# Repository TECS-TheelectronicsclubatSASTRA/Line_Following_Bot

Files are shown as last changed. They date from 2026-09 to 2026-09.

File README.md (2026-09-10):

# 🤖 Line-Following Bot — Autonomous PID-Controlled Line Tracker

> An autonomous line-following robot built on the **ESP32**, using a **5-channel IR sensor array** and a **PID control loop** for smooth, adaptive path tracking — including recovery from small gaps and complete line loss.






---

## 📖 Table of Contents

1. [Abstract](#-abstract)
2. [Key Features](#-key-features)
3. [System Architecture](#-system-architecture)
4. [Hardware Components](#-hardware-components)
5. [Pin Diagrams & Wiring](#-pin-diagrams--wiring)
6. [Power Design & Calculations](#-power-design--calculations)
7. [Software Stack](#-software-stack)
8. [Getting Started](#-getting-started)
9. [Firmware Overview](#-firmware-overview)
10. [Control Algorithm Details](#-control-algorithm-details)
11. [Calibration](#-calibration)
12. [Chassis Design](#-chassis-design)
13. [Results](#-results)
14. [Known Limitations & Future Work](#-known-limitations--future-work)
15. [Abbreviations](#-abbreviations)
---

## 🧾 Abstract

This project implements an **autonomous line-following robot** using an **ESP32** microcontroller, a **5-channel IR reflectance sensor array**, and a **TB6612FNG dual motor driver**. A closed-loop **PID (Proportional–Integral–Derivative) controller** continuously computes a weighted position error from the sensor array and translates it into differential motor speeds, allowing the bot to smoothly track a line, correct drift, and navigate curves.

The system also includes **gap-tolerance logic** (to glide over short broken segments of the line) and a **line-recovery routine** (pivoting toward the last known error direction when the line is completely lost). The chassis is a fully custom design, modeled in **Fusion 360**.

---

<p align="center">
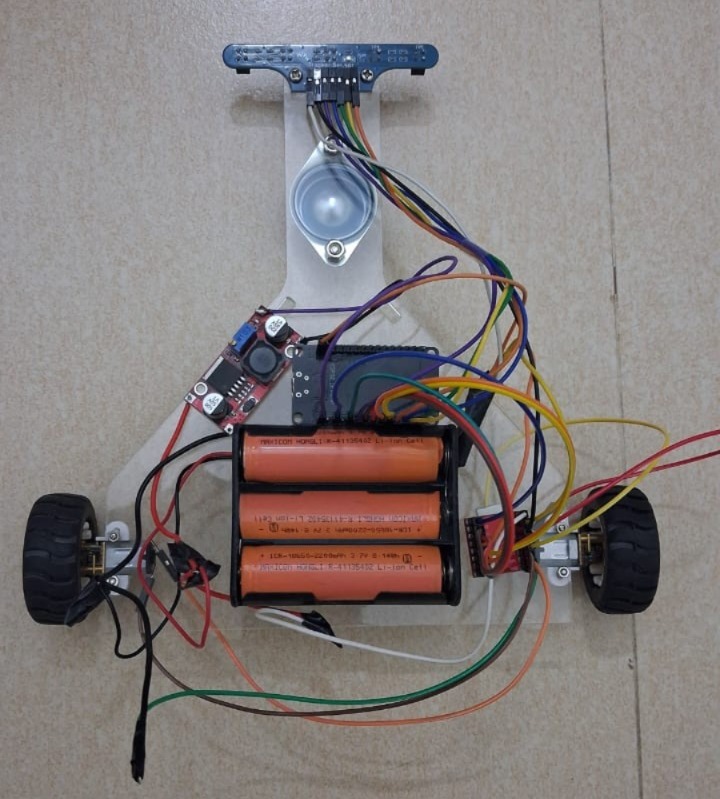
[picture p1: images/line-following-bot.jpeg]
  
</p>

---

## ✨ Key Features

| Feature | Description |
|---|---|
| 🎯 **Weighted Error Calculation** | 5 IR sensors mapped to weights `{-2,-1,0,1,2}` produce a continuous position error, not just discrete on/off states |
| 🧮 **Full PID Control Loop** | Proportional, Integral, and Derivative terms combine to produce smooth, non-oscillatory corrections |
| ⚙️ **Differential Motor Speed Control** | Left/right motor speeds are independently adjusted via PWM based on the computed correction |
| 🕳️ **Gap Tolerance** | Bot continues straight through short line breaks (< 50 ms) instead of veering off |
| 🔄 **Line-Recovery Pivot** | If the line is lost beyond the gap tolerance, the bot pivots in the direction of the last known error until it reacquires the line |
| 🔋 **Isolated Power Domains** | Battery pack powers the motor driver directly; a buck converter steps down voltage for the ESP32 logic rail |
| 🧩 **Custom Chassis** | Fully custom-modeled chassis designed in Fusion 360 |

---

## 🏗️ System Architecture

```
┌────────────────────┐        Analog Voltage (x5)         ┌──────────────────────┐
│  IR Tracker Module │ ──────────────────────────────▶   │        ESP32          │
│  (5 x IR Sensors)  │                                    │  (PID Control Logic) │
└────────────────────┘                                    └──────────┬───────────┘
                                                                     │ PWM + Direction Pins
                                                                     ▼
                                                          ┌────────────────────────┐
                                                          │     TB6612FNG          │
                                                          │   Dual Motor Driver    │
                                                          └───────────┬────────────┘
                                                                      │
                                                        ┌─────────────┴─────────────┐
                                                        ▼                           ▼
                                                 N20 Motor (Left)           N20 Motor (Right)
```

**Data flow summary:**
1. The 5-channel IR array reads analog reflectance values off the track surface.
2. Each reading is thresholded into a binary state (`0` = WHITE, `1` = BLACK / line).
3. Binary states are multiplied by positional weights and averaged to compute a single `error` value representing the bot's offset from the line's center.
4. The `error` is fed through the PID formula to compute a `correction` term.
5. `baseSpeed ± correction` produces independent left/right PWM duty cycles, sent to the TB6612FNG.
6. The TB6612FNG drives the two N20 motors accordingly, steering the bot back toward the line.

---

## 🔩 Hardware Components

| Component | Quantity | Purpose |
|---|---|---|
| ESP32 Development Board | 1 | Central MCU — sensor reading, PID computation, PWM generation |
| Waveshare IR Tracker Module | 5 channels (1 module) | Line detection via analog reflectance sensing |
| TB6612FNG Motor Driver | 1 | Drives both N20 motors with independent PWM + direction control |
| N20 Motor, 12V, 600 RPM | 2 | Drive motors (left & right) |
| 18650 Li-ion Cell | 3 | 11.1V battery pack — primary power source |
| Buck Converter (LM2596-based) | 1 | Steps down 11.1V pack voltage to power the ESP32 logic rail |
| Custom Chassis (Fusion 360) | 1 | Structural frame housing all components |

---

## 🔌 Pin Diagrams & Wiring

### IR Sensor → ESP32

| Sensor Position | Signal | ESP32 Pin |
|---|---|---|
| Far Left (L2) | ir1 | GPIO 27 |
| Left (L1) | ir2 | GPIO 34 |
| Center (C) | ir3 | GPIO 36 (VP) |
| Right (R1) | ir4 | GPIO 39 (VN) |
| Far Right (R2) | ir5 | GPIO 35 |

### TB6612FNG → ESP32

| ESP32 Pin | TB6612FNG Signal | Notes |
|---|---|---|
| GPIO 13 | PWMA | Left motor speed (PWM) |
| GPIO 14 | PWMB | Right motor speed (PWM) |
| GPIO 25 | IN1 | Left motor direction bit 1 |
| GPIO 26 | IN2 | Left motor direction bit 2 |
| GPIO 32 | IN3 | Right motor direction bit 1 |
| GPIO 33 | IN4 | Right motor direction bit 2 |
| GND | GND | Common ground — must tie ESP32, driver, and battery grounds together |

> ⚠️ **Critical wiring rule:** The IR tracker module, ESP32, TB6612FNG, and both battery packs must all share a **common ground**. The buck converter regulates the 11.1V pack down for the ESP32's logic rail; the TB6612FNG and motors are powered directly from the 11.1V pack.

### Full Circuit Diagram

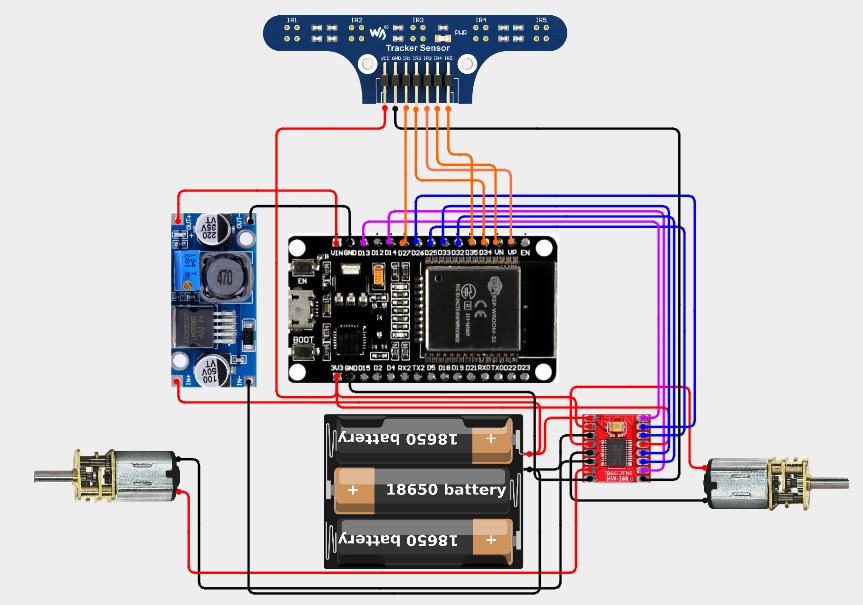
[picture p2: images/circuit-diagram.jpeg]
Circuit Diagram


---

## 🔋 Power Design & Calculations

| Metric | Value | Basis |
|---|---|---|
| Battery pack voltage | 11.1V | 3 × 3.7V 18650 Li-ion cells (series) |
| N20 motor rated voltage | 12V | Slightly under-driven by the 11.1V pack (acceptable — no full-speed requirement) |
| N20 motor rated speed | 600 RPM | At rated voltage, no load |
| ESP32 logic voltage | 3.3V (regulated via onboard LDO) | Fed from buck converter output |
| Motor driver supply (VM) | 11.1V | Direct from battery pack |
| Motor driver logic supply (VCC) | 3.3V–5V | From ESP32 or buck converter rail |

**Design rationale:** The motor driver and motors are powered directly from the 11.1V pack to avoid unnecessary voltage drop, while the ESP32 and sensor logic run off a separate regulated rail via the buck converter — isolating noisy motor current transients from the microcontroller's supply and reducing the risk of brown-outs during motor stalls or direction changes.

---

## 🖥️ Software Stack

| Layer | Technology |
|---|---|
| Firmware | C++ (Arduino framework for ESP32) |
| PWM Generation | ESP32 `ledc` API (`ledcAttach`, `ledcWrite`) |
| Sensing | `analogRead()` on 5 IR channels |
| Control Algorithm | Custom PID implementation (weighted-average error) |
| IDE / Toolchain | Arduino IDE with ESP32 board support |
| Mechanical Design | Autodesk Fusion 360 (chassis, exported as DXF) |

---

## 🚀 Getting Started

### 1. Prerequisites
- [Arduino IDE](https://www.arduino.cc/en/software) with ESP32 board package installed
- USB cable for flashing the ESP32
- Fully assembled hardware per the [Pin Diagrams & Wiring](#-pin-diagrams--wiring) section

### 2. Wiring
Follow the [Pin Diagrams & Wiring](#-pin-diagrams--wiring) section and the circuit diagram above. Double-check common ground across the ESP32, TB6612FNG, and battery packs before powering on.

### 3. Flashing the Firmware
```bash
# In Arduino IDE:
# 1. Select Board: "ESP32 Dev Module"
# 2. Select the correct COM/serial port
# 3. Open the .ino sketch from this repository
# 4. Click Upload
```

### 4. Running the Bot
1. Place the bot on the track with the IR array centered over the line.
2. Power on via the 18650 battery pack.
3. The bot will begin tracking the line immediately using the PID loop.
4. Monitor live sensor/error data via Serial Monitor at `115200` baud.

---

## 🧠 Firmware Overview

### Core Data Structures
```cpp
const int weights[5] = {-2, -1, 0, 1, 2};   // positional weight per sensor
float previousError = 0;
float integralError = 0;
```

### Key Functions

| Function | Role |
|---|---|
| `setMotors(leftSpeed, rightSpeed)` | Sets motor direction pins and writes constrained PWM values to both motors |
| `loop()` | Reads all 5 IR sensors, computes binary states, calculates weighted error, runs the PID formula, and calls `setMotors()` |
| Gap/Recovery block (inside `loop()`) | Detects when all sensors read WHITE; continues straight for short durations, then pivots toward the last known error if the line stays lost |

---

## 🎛 Control Algorithm Details

1. **Binary Thresholding:** Each of the 5 analog readings is compared against a threshold (`1700`). Values above → WHITE (`0`); values below → BLACK (`1`, the line).
2. **Weighted Error:**
   ```
   error = Σ(binary[i] × weight[i]) / Σ(binary[i])
   ```
   This gives a continuous value representing how far off-center the line is — not just "left/right."
3. **PID Correction:**
   ```
   correction = Kp × error + Ki × integralError + Kd × derivative
   ```
   - `Kp = 18`, `Ki = 0.2`, `Kd = 7` (tuned for the current chassis/track)
   - `integralError` is clamped to ±50 to prevent windup
4. **Speed Mapping:**
   ```
   leftSpeed  = baseSpeed + correction
   rightSpeed = baseSpeed - correction
   ```
5. **Gap Tolerance:** If all sensors read WHITE for less than 50 ms, the bot assumes a small gap and continues straight at `baseSpeed`.
6. **Line Recovery:** If the line stays lost beyond 50 ms, the bot pivots in-place toward whichever side `previousError` last indicated, until the line is reacquired.

---

## 🎚 Calibration

The threshold value (`1700`) is tuned for the specific track surface and lighting conditions used during testing. To recalibrate for a different track:

1. Open the Serial Monitor at `115200` baud.
2. Record raw analog readings over plain WHITE surface and over the BLACK line.
3. Set the threshold roughly halfway between the two averages.
4. Re-tune `Kp`, `Ki`, `Kd`, `baseSpeed`, and `pivotSpeed` as needed for the new track's curvature and desired speed.

---

## 🧩 Chassis Design

The chassis was custom-designed in **Fusion 360**.

<p align="center">
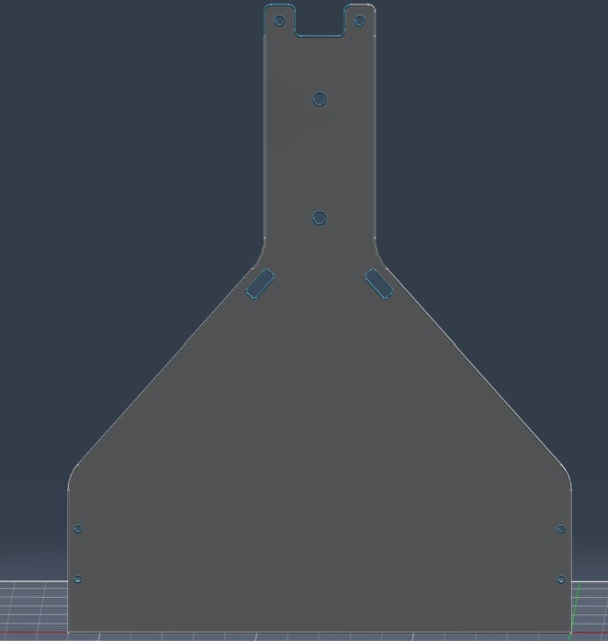
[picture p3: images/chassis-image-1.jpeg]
  
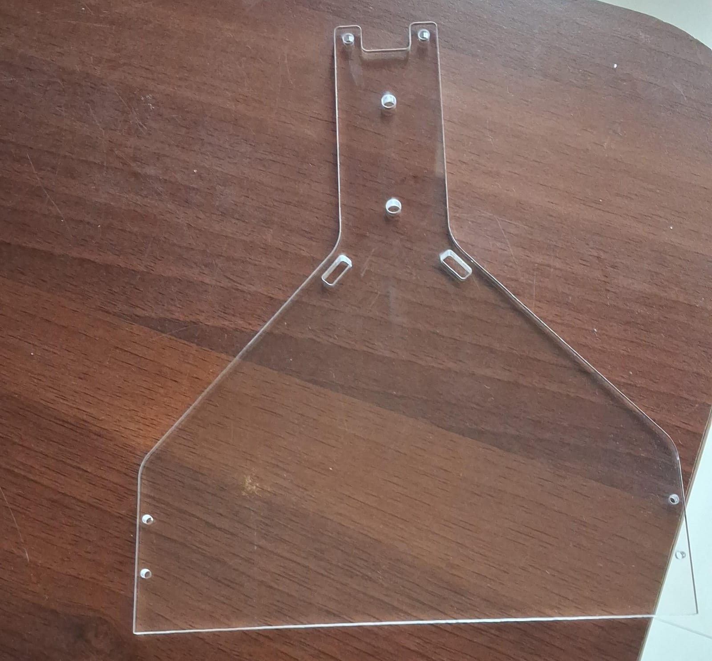
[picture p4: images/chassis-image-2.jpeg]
  
</p>

---

## 📊 Results

- ✅ Successfully built a functional line-following bot capable of tracking curved paths using closed-loop PID control.
- ✅ Verified smooth cornering behavior via tuned `Kp`/`Ki`/`Kd` constants, avoiding oscillation around the line center.
- ✅ Validated gap-tolerance logic on tracks with intentional small breaks (`- - -` style segments).
- ✅ Verified line-recovery pivot behavior when the bot fully overshoots a sharp turn.

*(Full run photos/video to be added.)*

---

## 🔮 Known Limitations & Future Work

- PID constants (`Kp`, `Ki`, `Kd`) are hand-tuned for one specific track/lighting setup — not self-calibrating across surfaces.
- Threshold-based binary conversion (`1700`) is sensitive to ambient lighting changes; a dynamic/auto-calibration routine would improve robustness.
- No onboard display or telemetry — debugging currently relies on wired Serial Monitor output.
---

## 🔤 Abbreviations

| Abbreviation | Full Form |
|---|---|
| IR | Infrared |
| PID | Proportional–Integral–Derivative |
| PWM | Pulse Width Modulation |
| MCU | Micro-Controller Unit |
| RPM | Revolutions Per Minute |
| GPIO | General Purpose Input/Output |

---

<p align="center"><i>Built as a hands-on embedded systems project — combining sensor fusion, closed-loop control, and custom mechanical design into one autonomous bot.</i></p>

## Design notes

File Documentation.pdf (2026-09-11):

# AUTONOMOUS PID-CONTROLLED LINE-FOLLOWING BOT

## ABSTRACT

This project presents the design, implementation, and evaluation of an autonomous line-following robotic system driven by an ESP32 microcontroller, a 5-channel infrared (IR) reflectance sensor array, and a TB6612FNG dual motor driver. The system employs a closed-loop Proportional–Integral–Derivative (PID) control algorithm to continuously compute positional error from the sensor array and dynamically regulate differential motor speeds via Pulse Width Modulation (PWM). Advanced firmware routines, including gap-tolerance filtering and dynamic line-recovery pivoting, ensure smooth trajectory tracking and stability during track discontinuities or severe overshoot conditions. Hardware power management utilizes isolated logic and drive rails to mitigate electromagnetic interference and voltage drops. The mechanical frame features a custom-engineered chassis developed in Fusion 360. Practical applications demonstrate robust human-machine interaction, real-time embedded control, and sensor fusion in autonomous mobile robotics.

## LIST OF FIGURES

S.No | Figure Description | Page / Section
Fig. 1 | System Block Diagram & Control Pipeline | Section 3
Fig. 2 | Complete Circuit Diagram | Section 5
Fig. 3 | Custom Chassis Isometric Views (Fusion 360) | Section 12

## LIST OF ABBREVIATIONS

Abbreviation | Full Form
IoT | Internet of Things
LED | Light Emitting Diode
IR | Infrared
MCU | Micro-Controller Unit
PID | Proportional–Integral–Derivative
PWM | Pulse Width Modulation
GPIO | General Purpose Input/Output
DC | Direct Current
LDO | Low Dropout Regulator
RPM | Revolutions Per Minute

## NOTATION

Notation | Physical / Electrical Quantity

V Volts (Voltage)

mV | Millivolts

A Amperes (Current)

mA | Milliamperes
| Ohms (Resistance)
MHz | Megahertz (Frequency)
ms | Milliseconds (Time)

## 1. INTRODUCTION

### 1.1. Background and Motivation

Autonomous mobile robots rely heavily on precise sensor feedback and real-time control algorithms to navigate structured environments. Line-following robots represent a foundational benchmark in control systems engineering. Traditional line followers rely on basic threshold-based (bang-bang) control, leading to oscillations, jerky movements, and frequent line loss.

This project addresses these limitations by integrating a multi-channel analog sensor array with a closed-loop PID control algorithm. Using an ESP32 microcontroller, the system computes a weighted continuous error value to execute smooth, adaptive path tracking over varying curvatures and line breaks.

### 1.2. System Overview

The physical platform utilizes a 5-channel IR reflectance tracker module mounted at the front chassis. The analog voltage output from each sensor is acquired by the ESP32's Analog-to-Digital Converters (ADC). The system converts these signals into continuous positional error values, which are processed through digital PID filtering to calculate differential drive correction signals. A TB6612FNG dual H-bridge motor driver receives these PWM signals to control two high-torque N20 gear motors.

### 1.3. Power Architecture and Connectivity

To ensure system stability, the power architecture separates logic power from motor drive power. High-current transients caused by motor direction switching can cause brown-outs on microcontroller rails. The primary supply is an 11.1 V (3S) Li-ion battery pack powering the motors directly via the TB6612FNG, while a discrete LM2596 buck converter steps down the supply voltage to power the ESP32 and sensor arrays safely.

### 1.4. Workflow and Engineering Track

The development lifecycle was divided into three modular technical tracks:
1. Embedded Hardware Track: Circuit schematic design, power domain isolation, motor driver interfacing, and chassis fabrication.
2. Firmware Track: Real-time C++ control logic, multi-channel ADC acquisition, PID algorithm implementation, and fault-recovery routines.
3. Control & Mechanical Track: CAD modeling in Fusion 360, PID tuning parameter
optimization ( | ), and track response benchmarking.

## 2. SYSTEM ARCHITECTURE

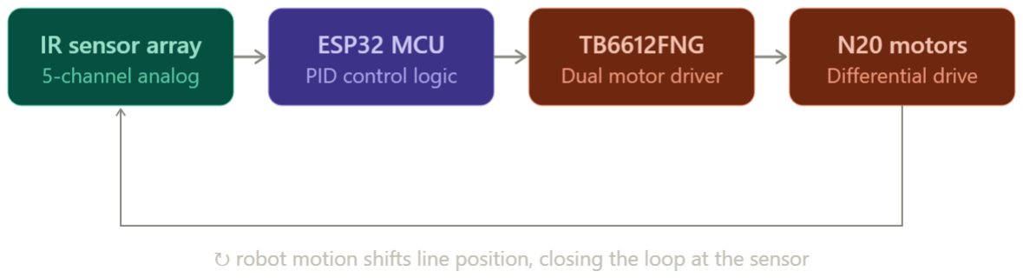
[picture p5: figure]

### Data Flow Pipeline:

1. Acquisition: The 5-channel IR array samples track reflectance levels continuously.
2. Binarization: Each analog channel is thresholded into binary states (0 for light surface, 1 for dark track).
3. Positional Weighting: Spatial weights | translate binary array states

into a single scalar error parameter ( ).

4. PID Calculation: Digital PID terms derive a correction signal ( ) from the calculated error.
5. PWM Signal Generation: Motor drive signals ( | ) are
calculated using baseSpeed | .
6. Execution: The TB6612FNG modifies current delivery to the N20 motors to adjust the robot's heading.

## 3. HARDWARE SPECIFICATIONS AND BILL OF MATERIALS

### 3.1. Required Components

Item | Component Description | Operating Parameters | Quantity
1 | ESP32 Development Board | 240 MHz Dual-Core, 3.3 V Logic | 1
2 | Waveshare 5-Channel IR Tracker | 5-Channel Reflectance Array | 1
3 | TB6612FNG Dual Motor Driver | Max continuous per channel | 1
4 | N20 Micro Gear Motors | Rated , | 2
5 | 18650 Li-ion Cells | , per cell (Series 3S) | 3
6 | LM2596 Step-Down Buck Converter | Adjustable DC-DC, switched output | 1
7 | Custom Frame Assembly | Fusion 360 Custom CAD Design | 1

## CUSTOM CHASIS (FUSION 360:

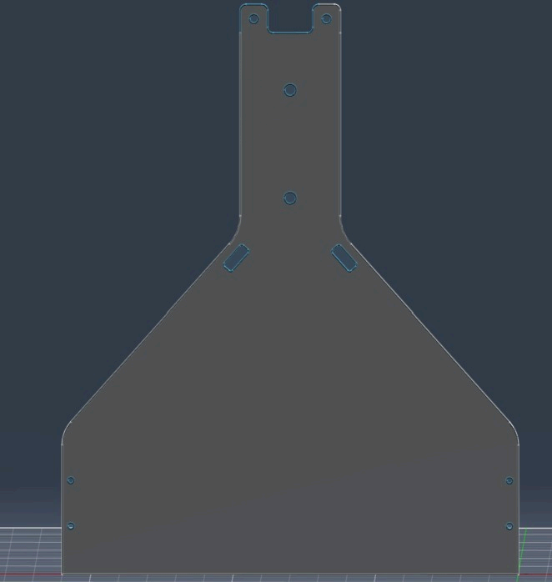
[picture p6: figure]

## 4. PIN AND HARDWARE INTERFACING

### 4.1. IR Sensor Interfacing to ESP32

Sensor Channel | Position Weight | Function / Signal | ESP32 Pin
Far Left ( ) | | ir1 | GPIO 27
Left ( ) | | ir2 | GPIO 34
Center ( ) | | ir3 | GPIO 36 (VP)
Right ( ) | | ir4 | GPIO 39 (VN)
Far Right ( ) | | ir5 | GPIO 35

### 4.2. Motor Driver Interfacing to ESP32

ESP32 Pin | TB6612FNG Pin | Functional Description
GPIO 13 | PWMA | Left Motor Speed Control (PWM Output)
GPIO 14 | PWMB | Right Motor Speed Control (PWM Output)
GPIO 25 | IN1 | Left Motor Direction Input Bit 1
GPIO 26 | IN2 | Left Motor Direction Input Bit 2
GPIO 32 | IN3 | Right Motor Direction Input Bit 1
GPIO 33 | IN4 | Right Motor Direction Input Bit 2

GND | GND | Common Logic and Power Ground System

## 5. POWER CALCULATIONS AND MANAGEMENT

### 5.1. Voltage Distribution Analysis

- Primary Battery Pack Supply ( | ):
- Motor Driver Motor Rail ( | ): Directly connected to | ( | ), matching the
operating range of the | rated N20 motors.
- Microcontroller and Sensor Rail ( | ): Stepped down via the LM2596 buck converter
to | , then regulated to | by the ESP32's onboard LDO.

### 5.2. Current and Power Calculations

- N20 Motor Current Draw:
- Stall Current ( | ): ~ | per motor at | .
- Operational Drive Current ( | ): ~ | per motor.
- Total Peak Drive Current ( | ):
- Logic Current Draw:
- ESP32 Operating Current ( | ): ~ | (active processing).
- IR Sensor Array Draw ( | ): ~ | .
- Total Logic Current ( | ):
- Total Dynamic Peak Load:

## COMPLETE CIRCUIT DIAGRAM

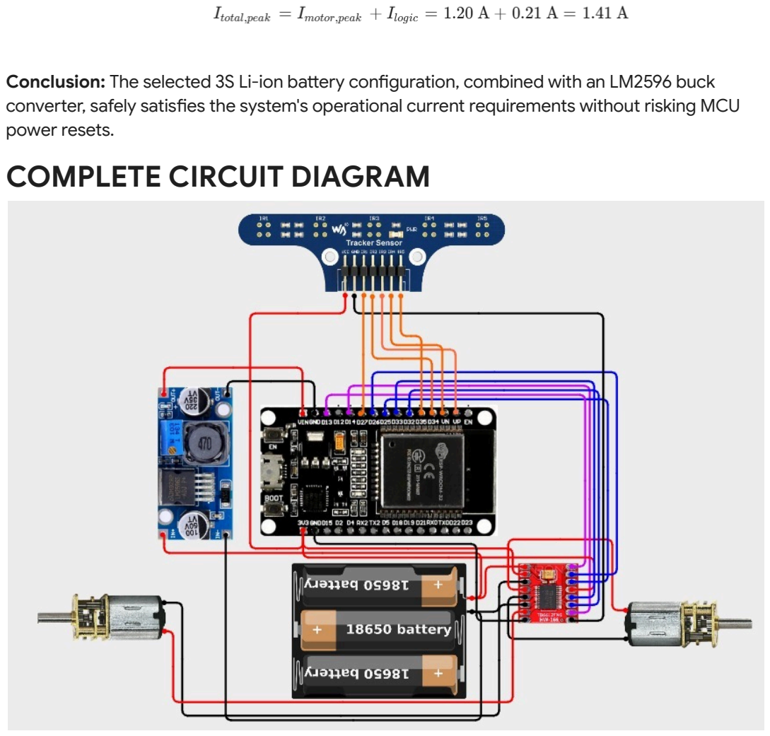
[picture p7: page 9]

Conclusion: The selected 3S Li-ion battery configuration, combined with an LM2596 buck converter, safely satisfies the system's operational current requirements without risking MCU power resets.

## 6. FIRMWARE AND CONTROL ALGORITHM IMPLEMENTATION

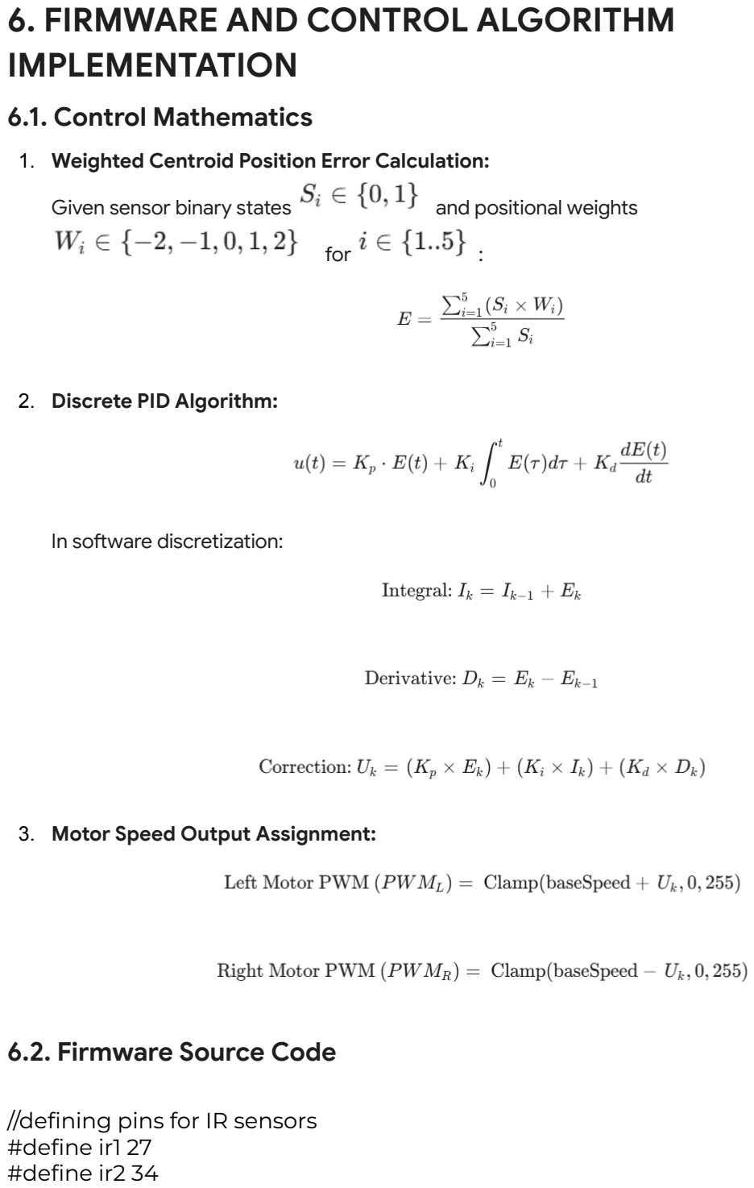
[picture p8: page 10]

### 6.1. Control Mathematics

1. Weighted Centroid Position Error Calculation:
Given sensor binary states | and positional weights
for | :
2. Discrete PID Algorithm:

In software discretization:

3. Motor Speed Output Assignment:

### 6.2. Firmware Source Code

//defining pins for IR sensors #define ir1 27
#define ir2 34

#define ir3 36 //SensorVP -> VP #define ir4 39 //SensorVN -> VN #define ir5 35

//defining pins for motor driver #define PWMA 13
#define PWMB 14

#define IN1 25

#define IN2 26

#define IN3 32

#define IN4 33

//weights for each IR sensor const int weights[5] = {-2,-1,0,1,2};

//Proportionality constant const float Kp = 18;
//Derivative constant
const float Kd = 7;
//Integral constant
const float Ki = 0.2;

//default speed for bot
const float baseSpeed = 110; const float pivotSpeed = 100; const float minSpeed = 0;

float previousError = 0;
float integralError = 0;
const float integralLimit = 50;

//for small gaps in between like -> "---"
unsigned long lostLineTime = 0;
const int gapTolerance = 50; //50 ms

void setMotors(float leftSpeed,float rightSpeed){ digitalWrite(IN1, HIGH);
digitalWrite(IN2, LOW);
digitalWrite(IN3, HIGH);
digitalWrite(IN4, LOW);

ledcWrite(PWMA, constrain(leftSpeed, minSpeed, 255)); ledcWrite(PWMB, constrain(rightSpeed, minSpeed, 255)); }

void setup() {
Serial.begin(115200);
pinMode(IN1, OUTPUT);
pinMode(IN2, OUTPUT);
pinMode(IN3, OUTPUT);
pinMode(IN4, OUTPUT);
//pinMode(STBY, OUTPUT);

pinMode(ir1, INPUT);
pinMode(ir2, INPUT);
pinMode(ir3, INPUT);
pinMode(ir4, INPUT);
pinMode(ir5, INPUT);

//setting up the frequency and resolution of the PWM ledcAttach(PWMA, 1000, 8);
ledcAttach(PWMB, 1000, 8);
//digitalWrite(STBY, HIGH);
}

void loop() {
int l2 = analogRead(ir1);
int l1 = analogRead(ir2);
int c = analogRead(ir3);
int r1 = analogRead(ir4);
int r2 = analogRead(ir5);

int readings[5] = {l2,l1,c,r1,r2}; int binary[5];
int multi[5];

float multiSum = 0;
float sum = 0;
float error = 0;

//converting the values to 0 or 1
for(int i=0;i<5;i++){
//threshold value is set as 1700 considering all readings from calibrated values!
if(readings[i] > 1700){
binary[i] = 0; //WHITE -> 0
}
else{
binary[i] = 1; //BLACK -> 1 }

multi[i] = binary[i] * weights[i]; multiSum += multi[i];
sum += binary[i];
}
//if all sensors detect WHITE then, division by zero will occur -> gotta prevent that!
if(sum !=0){
lostLineTime = 0;
error = multiSum / sum; //error tells how far the bot is away from the centre integralError += error;
integralError = constrain(integralError, -integralLimit, integralLimit);

float derivative = error - previousError;
float crct = Kp*error + Ki*integralError + Kd*derivative;

previousError = error;

float lsp = baseSpeed + crct;
float rsp = baseSpeed - crct;
setMotors(lsp, rsp);
}
else{
unsigned long now = millis(); if(lostLineTime == 0){
lostLineTime = now;
}
unsigned long lostDuration = now - lostLineTime; if(lostDuration < gapTolerance){ setMotors(baseSpeed, baseSpeed);
}
else{
integralError = 0;
if(previousError >= 0){
digitalWrite(IN1, HIGH);
digitalWrite(IN2, LOW);
digitalWrite(IN3, LOW);
digitalWrite(IN4, HIGH);
ledcWrite(PWMA, pivotSpeed); ledcWrite(PWMB, pivotSpeed); }
if(previousError < 0){
digitalWrite(IN1, LOW);
digitalWrite(IN2, HIGH);
digitalWrite(IN3, HIGH);
digitalWrite(IN4, LOW);

ledcWrite(PWMA, pivotSpeed); ledcWrite(PWMB, pivotSpeed); }
}
}
//Serial.println("Error: "+String(error));
Serial.println("Sensor Readings: "+String(l2)+" "+String(l1)+" "+String(c)+" "+String(r1)+" "+String(r2));
Serial.println("Binary readings:");
for(int i=0;i<5;i++){
Serial.print(String(binary[i])+ " "); }
Serial.println("");
}

## 7. RESULTS AND DISCUSSION

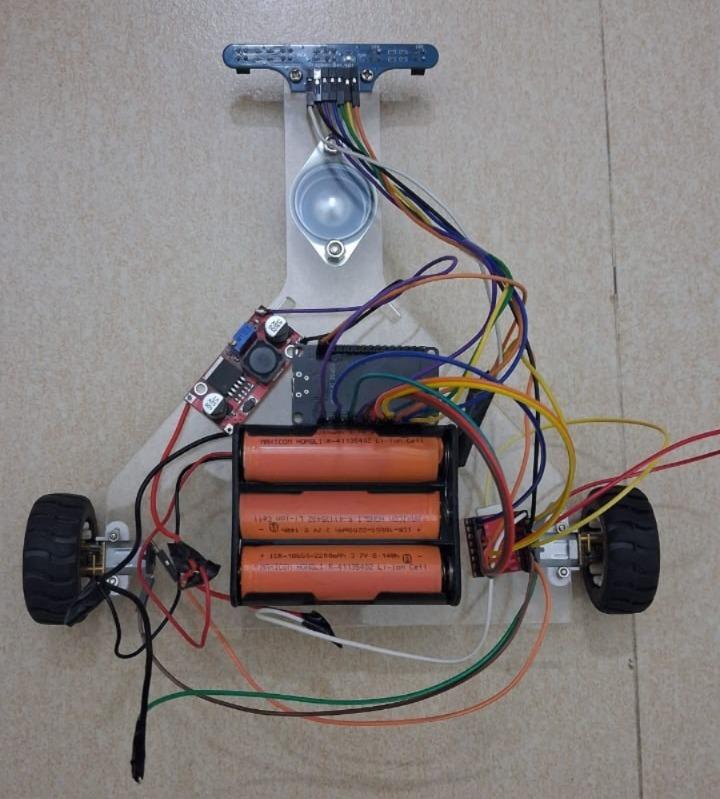
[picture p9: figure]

### 7.1. Experimental Performance Metrics

The system was evaluated across multiple track geometries with varying turn radii ( | to
) and track gaps ( | to | ).
- Continuous Path Tracking: The closed-loop PID controller suppressed oscillations on straight tracks and minimized overshoot on curved segments.
- Gap Navigation Response: The 50 ms inertia-driven gap tolerance allowed the bot to
traverse track disruptions up to | in length without veering off course.
- Line Recovery Validation: When overshooting sharp | turns, the bot successfully
pivoted in the direction of the last recorded error vector until line acquisition was restored.

## 8. CONCLUSION

The design and hardware implementation of the Autonomous PID-Controlled Line-Following Bot were completed successfully. By integrating an ESP32 microcontroller, a 5-channel reflectance sensor array, and an isolated dual motor drive system, the platform demonstrates reliable path tracking. The addition of anti-windup PID algorithms, gap tolerance filtering, and recovery-pivot logic ensures robust performance on complex track layouts.

## 9. REFERENCES

1. ESP32 Technical Reference Manual: https://www.espressif.com/en/support/documentation/documents
2. TB6612FNG Driver Datasheet: https://www.sparkfun.com/datasheets/Robotics/TB6612FNG.pdf
3. LM2596 DC-DC Converter Specifications: https://www.ti.com/lit/ds/symlink/lm2596.pdf

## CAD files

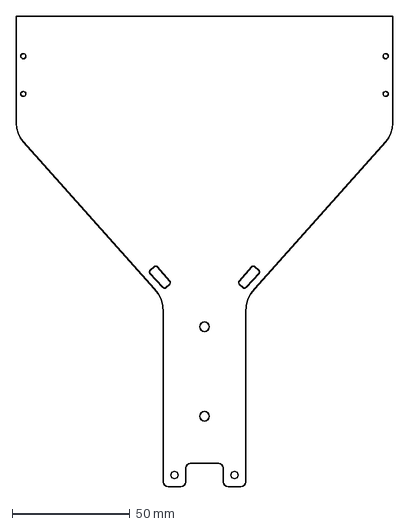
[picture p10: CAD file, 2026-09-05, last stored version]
chassis/chassis-sketch.dxf
160.0 x 200.0 mm
